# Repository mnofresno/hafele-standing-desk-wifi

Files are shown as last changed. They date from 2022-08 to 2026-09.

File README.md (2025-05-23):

# Hafele Standing Desk

## WiFi-Control Modification

### Overview

This project details the steps to modify a Hafele® Standing Desk to be controlled via WiFi.

## Table of Contents

1. [Overview](#overview)
2. [Hardware](#hardware)
   - [Materials](#materials)
   - [Case Design](#case-design)
   - [Renders of the Case](#renders-of-the-case)
3. [Software](#software)
   - [Firmware](#firmware)
   - [Firmware Compilation & Deployment](#firmware-compilation--deployment)
4. [System Features](#system-features)
5. [Technical Specifications](#technical-specifications)
6. [Contributing](#contributing)
7. [References](#references)

### Hardware

#### Materials

- **Printing Filament:**
  - Case: Approximately 52 grams and 17.46 meters
  - Lid: Approximately XX grams and YY meters

- **Electronics:**
  - **CPU:** Wemos D1 ESP32, 160~240 MHz, 320 KiB RAM
  - **Display:** OLED 128x64 px i2C SSD1306, viewable area: 14.7x26.7 mm
  - **Relay Module Shield:** 2 CH

#### Case Design

The case was parametrically designed using FreeCAD 0.0.19 with adjustable parameters:

- Length
- Height
- Width
- Display dimensions (width and height)
- Radius of curvature
- Panel angle
- Wall thickness
- Display position (x and y)
- Button distance
- Lid thickness
- Bolt diameter, length, and separation
- Inner diameter of bolt nuts

##### Provided Files

The following files are included in the `plastic_case` directory:

- `control_box.stl`: STL file for the main control box.
- `control_box_lid.stl`: STL file for the lid of the control box.
- `hafele_control_box_with_lid.FCStd`: FreeCAD source file for the control box and lid.
- `control_box_render.png`: Rendered image of the control box.
- `control_box_lid_render.png`: Rendered image of the control box lid.

#### Renders of the Case

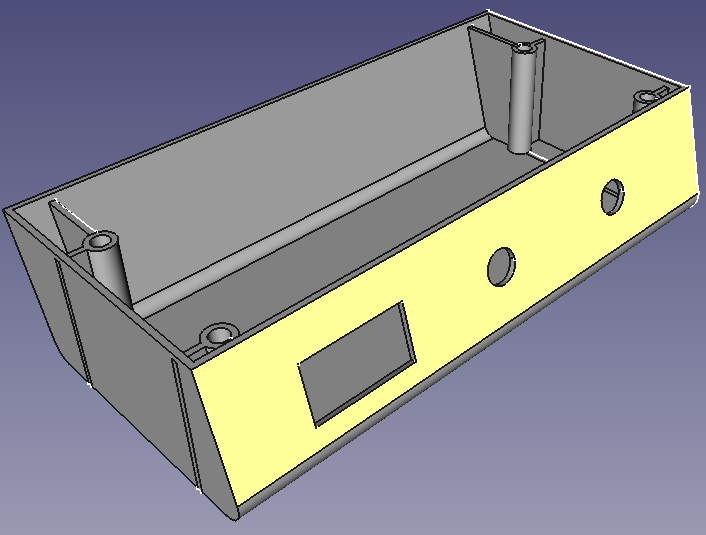
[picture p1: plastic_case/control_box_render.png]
Control Box Render

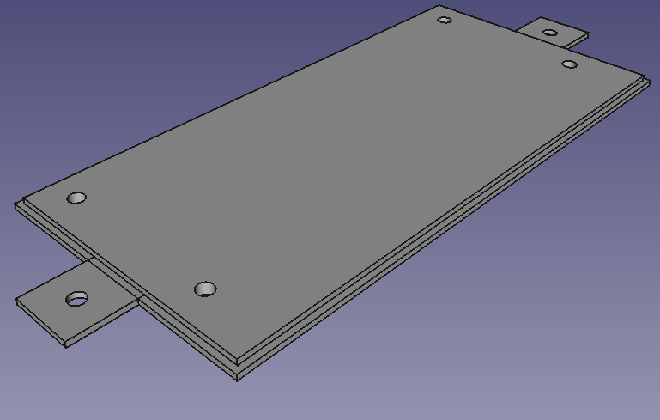
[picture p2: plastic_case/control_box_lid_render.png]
Control Box Lid Render


### Software

#### Firmware

The firmware was developed in Arduino C++, based on the [WiFi Manager platform](https://github.com/tzapu/WiFiManager).

Current version: v1.1.9

#### Firmware Compilation & Deployment

1. **Install Docker:**

   If you don't have Docker installed, follow the instructions [here](https://docs.docker.com/get-docker/).

2. **Compile the Source Code:**

   Run the `build.sh` script to compile the firmware using Docker:

   ```bash
   cd firmware
   ./build.sh
   ```

3. **Compile and Upload with OTA:**

   ```bash
   make TARGET_IP=x.x.x.x
   ```
   (Replace `x.x.x.x` with the device's IP address)

### System Features

#### Core Functionality
- Height adjustment with position memory (M1, M2)
- Real-time clock display
- System calibration
- Lock mode for safety
- Debug mode for troubleshooting

#### User Interface
- OLED display (128x64 pixels)
- Rotary encoder for navigation
- Two control buttons (Enter, Back)
- Intuitive menu system

#### Movement Control
- Continuous up/down movement
- One-second movement increments
- Full up/down positions
- Memory positions (M1, M2)
- Height limits with safety margins

### Technical Specifications

#### GPIO Configuration
- Motor Control:
  - Up Relay: GPIO32
  - Down Relay: GPIO33
- User Interface:
  - Enter Button: GPIO34
  - Back Button: GPIO35
  - Encoder A: GPIO18
  - Encoder B: GPIO19

#### System Limits
- Maximum Height: 1220mm
- Minimum Height: 725mm
- Safety Margin: 5mm

#### WiFi Configuration
- Default AP Name: "WIFI_STANDING_DESK"
- Default AP Password: "PASSWORD"
- Non-blocking configuration portal
- OTA update support

#### Dependencies
- WiFiManager: WiFi configuration
- Adafruit_GFX: Display graphics
- Adafruit_SSD1306: OLED display control
- ESP32Encoder: Rotary encoder handling
- ArduinoJson: JSON processing
- NTPClient: Time synchronization

#### Safety Features
- Watchdog Timer (2-second timeout)
- EEPROM error handling
- Movement limit validation
- Configuration validation
- Emergency stop functionality

### Contributing

For contributions, please send an email to the repository owner.

### References

- Photos of the case
- Screenshots of the STL file designed in FreeCAD

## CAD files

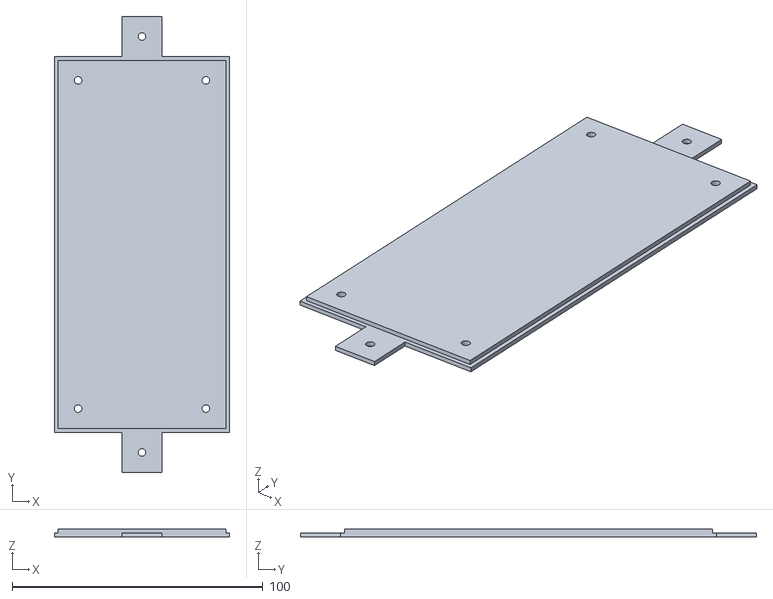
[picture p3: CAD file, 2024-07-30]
plastic_case/control_box_lid.stl
70.0 x 182.0 x 3.00

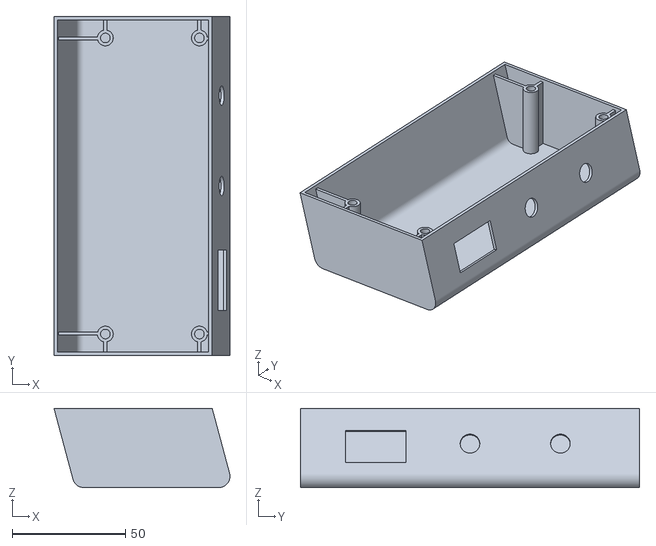
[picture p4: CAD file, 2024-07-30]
plastic_case/control_box.stl
77.9 x 150.0 x 35.0

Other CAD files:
plastic_case/hafele_control_box_with_lid.FCStd

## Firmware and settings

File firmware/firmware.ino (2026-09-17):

#include <assert.h>
#include <WiFiManager.h>
#include <SPI.h>
#include <Wire.h>
#include <Adafruit_GFX.h>
#include <Adafruit_SSD1306.h>
#include <ESP32Encoder.h>
#include <esp_task_wdt.h>
#include <ArduinoJson.h>

#include "MenuInstance.h"
#include "MotorDriver.h"
#include "Calibration.h"
#include "DebugInfo.h"
#include "DisplayHandler.h"
#include "ButtonsHandler.h"
#include "html/panel.h"
#include <WiFiUdp.h>
#include <NTPClient.h>
#include <ESPmDNS.h>
#include <esp_wifi.h>
#define __ASSERT_USE_STDERR

#define VERSION_STRING "v1.2.7"

#define DEFAULT_HOSTNAME "hafele-standing-desk"
#define DEFAULT_AP_NAME "WIFI_STANDING_DESK"
#define DEFAULT_AP_PASSWORD "PASSWORD"

#define SCREEN_WIDTH 128 // OLED display width, in pixels
#define SCREEN_HEIGHT 64 // OLED display height, in pixels

#define OLED_RESET     -1 // Reset pin # (or -1 if sharing Arduino reset pin)

#define STATE_CLOCK 0
#define STATE_MENU 1
#define STATE_WIFI_CONFIG 2
#define STATE_CALIBRATION 3
#define STATE_MEMORIES 4
#define STATE_MOVE 5
#define STATE_DEBUG_CONFIG 6
#define STATE_LOCKED 7

#define ITEM_INDEX_WIFI 1
#define ITEM_INDEX_MEMORIES 101
#define ITEM_INDEX_MOVE 2
#define ITEM_INDEX_DEBUG 3

#define ITEM_INDEX_MOVE_UP 4
#define ITEM_INDEX_MOVE_DOWN 5
#define ITEM_INDEX_MOVE_FULL_UP 6
#define ITEM_INDEX_MOVE_FULL_DOWN 7
#define ITEM_INDEX_MOVE_1SEC_UP 61
#define ITEM_INDEX_MOVE_1SEC_DOWN 71

#define ITEM_INDEX_CALIBRATION 8
#define ITEM_INDEX_CALIBRATION_CURRENT_POSITION 9
#define ITEM_INDEX_CALIBRATION_UP_SPEED 10
#define ITEM_INDEX_CALIBRATION_DOWN_SPEED 11
#define ITEM_INDEX_CALIBRATION_DOWN_STATUS 12
#define ITEM_INDEX_DISPLAY_TIMEOUT 17

#define ITEM_INDEX_MEMORIES_GOTO_M1 13
#define ITEM_INDEX_MEMORIES_GOTO_M2 14
#define ITEM_INDEX_MEMORIES_SET_M1 15
#define ITEM_INDEX_MEMORIES_SET_M2 16

#define UP_RELAY_PIN 32
#define DOWN_RELAY_PIN 33

#define ENTER_BUTTON_PIN 34
#define BACK_BUTTON_PIN 35

#define ENCODER_PIN_A 18
#define ENCODER_PIN_B 19

#define ARRAY_SIZE(array) (sizeof(array)/sizeof((array)[0]))
#define WDT_TIMEOUT 2
#define DISPLAY_TIMEOUT_MIN_SECONDS 0
#define DISPLAY_TIMEOUT_MAX_SECONDS 120
#define DISPLAY_TIMEOUT_STEP_SECONDS 10

ESP32Encoder encoder;
WiFiManager wifiManager;
WiFiManagerParameter wm_param_current_position_mm("current_position_mm", "Current Position (mm)", "position", 20);
WiFiManagerParameter wm_param_up_traverse_mm_sec("up_traverse_mm_sec", "Up traverse speed (mm/s)", "up traverse", 20);
WiFiManagerParameter wm_param_down_traverse_mm_sec("down_traverse_mm_sec", "Down traverse speed (mm/s)", "down traverse", 20);

Adafruit_SSD1306 display(SCREEN_WIDTH, SCREEN_HEIGHT, &Wire, OLED_RESET);
Calibration calibration_storage(&on_corrupted_eeprom);
MotorDriver motor_driver(UP_RELAY_PIN, DOWN_RELAY_PIN);
DisplayHandler display_handler(&display);
ButtonsHandler buttons_handler(ENTER_BUTTON_PIN, BACK_BUTTON_PIN, true);
DebugInfo debug_info(&display_handler, &buttons_handler);
WiFiUDP ntpUDP;
NTPClient timeClient(ntpUDP, "pool.ntp.org", -10800, 3600000);

const char* get_state_name(int state) {
    switch (state) {
        case STATE_CLOCK: return "STATE_CLOCK";
        case STATE_MENU: return "STATE_MENU";
        case STATE_WIFI_CONFIG: return "STATE_WIFI_CONFIG";
        case STATE_CALIBRATION: return "STATE_CALIBRATION";
        case STATE_MEMORIES: return "STATE_MEMORIES";
        case STATE_MOVE: return "STATE_MOVE";
        case STATE_DEBUG_CONFIG: return "STATE_DEBUG_CONFIG";
        case STATE_LOCKED: return "STATE_LOCKED";
        default: return "UNKNOWN_STATE";
    }
}

MenuItem main_menu[] = {
    {ITEM_INDEX_WIFI, "WiFi Cfg."},
    {ITEM_INDEX_CALIBRATION, "Calibr."},
    {ITEM_INDEX_MEMORIES, "Memories"},
    // {ITEM_INDEX_CLOCK, "Clock"},
    {ITEM_INDEX_MOVE, "Move"},
    // {ITEM_INDEX_DEBUG, "Debug"},
};

MenuItem move_menu[] = {
    {ITEM_INDEX_MOVE_UP, "Up"},
    {ITEM_INDEX_MOVE_DOWN, "Down"},
    {ITEM_INDEX_MOVE_FULL_UP, "Full-Up"},
    {ITEM_INDEX_MOVE_FULL_DOWN, "Full-Down"},
    {ITEM_INDEX_MOVE_1SEC_UP, "1 sec. UP"},
    {ITEM_INDEX_MOVE_1SEC_DOWN, "1 sec. DN"},
};

MenuItem calibration_menu[] = {
    {ITEM_INDEX_CALIBRATION_CURRENT_POSITION, "Pos:"},
    {ITEM_INDEX_CALIBRATION_UP_SPEED, "Up:"},
    {ITEM_INDEX_CALIBRATION_DOWN_SPEED, "Dn:"},
    {ITEM_INDEX_CALIBRATION_DOWN_STATUS, "St:"},
    {ITEM_INDEX_DISPLAY_TIMEOUT, "Off:"},
};

MenuItem memories_menu[] = {
    {ITEM_INDEX_MEMORIES_GOTO_M1, "M1 999 mm"},
    {ITEM_INDEX_MEMORIES_GOTO_M2, "M2 111 mm"},
    {ITEM_INDEX_MEMORIES_SET_M1, "Set M1"},
    {ITEM_INDEX_MEMORIES_SET_M2, "Set M2"},
};

MenuInstance main_menu_instance(
    &display_handler,
    main_menu,
    ARRAY_SIZE(main_menu),
    "Menu: (.)",
    &buttons_handler
);

MenuInstance move_menu_instance(
    &display_handler,
    move_menu,
    ARRAY_SIZE(move_menu),
    "Move:",
    &buttons_handler
);

MenuInstance calibration_menu_instance(
    &display_handler,
    calibration_menu,
    ARRAY_SIZE(calibration_menu),
    "Calib:",
    &buttons_handler
);

MenuInstance memories_menu_instance(
    &display_handler,
    memories_menu,
    ARRAY_SIZE(memories_menu),
    "Mem:",
    &buttons_handler
);

int current_state = STATE_MENU;
int next_state = STATE_MENU;
static bool wdt_is_enabled = false;
CalibrationData calibration;
bool is_wifi_enabled = true;
int use_ap_or_station = WIFI_STA;
bool is_display_locked = false;
bool wifi_currently_connected = false;
unsigned long last_display_activity_millis = 0;
int64_t last_activity_encoder_position = 0;
int last_activity_enter_level = HIGH;
int last_activity_back_level = HIGH;
bool display_is_off = false;

void on_corrupted_eeprom() {
    display_handler.print_full_screen_with_title("Invalid Cfg.", "Restore default...");
}

void setup() {
    Serial.begin(115200);
    Serial.println();
    Serial.println("Starting Serial Port...");

    display_handler.draw_starting(VERSION_STRING);
    config_inputs_and_outputs();

    ESP32Encoder::useInternalWeakPullResistors=UP;
  	encoder.attachHalfQuad(ENCODER_PIN_B, ENCODER_PIN_A);

    last_activity_encoder_position = encoder.getCount();
    last_activity_enter_level = digitalRead(ENTER_BUTTON_PIN);
    last_activity_back_level = digitalRead(BACK_BUTTON_PIN);
    last_display_activity_millis = millis();

    WiFi.mode(WIFI_STA);
    WiFi.setHostname(DEFAULT_HOSTNAME);
    MDNS.begin(DEFAULT_HOSTNAME);

    calibration_storage.fetch(calibration);

    setup_wifi_manager();

    calibration_menu_instance.setFontSize(2);

    motor_driver.setOnCalibrationChangedCallback(&store_calibration);
    motor_driver.setCalibrationData(&calibration);
    timeClient.begin();
}

void setup_wifi_manager() {
    wifiManager.setConfigPortalBlocking(false);

    wifiManager.setPreOtaUpdateCallback(&on_pre_ota_update);
    wifiManager.setTitle("WIFI STANDING DESK");

    update_calibration_parameters();

    wifiManager.setParamsPage(true);
    wifiManager.setSaveParamsCallback(&on_params_save);
    wifiManager.addParameter(&wm_param_current_position_mm);
    wifiManager.addParameter(&wm_param_up_traverse_mm_sec);
    wifiManager.addParameter(&wm_param_down_traverse_mm_sec);

    wifiManager.setWebServerCallback(&config_api_endpoints);

    wifiManager.startWebPortal();
}

void update_calibration_parameters() {
    wm_param_current_position_mm.setValue(String(calibration.current_position_mm).c_str(), 20);
    wm_param_up_traverse_mm_sec.setValue(String(calibration.up_traverse_mm_sec).c_str(), 20);
    wm_param_down_traverse_mm_sec.setValue(String(calibration.down_traverse_mm_sec).c_str(), 20);
}

void store_calibration() {
    update_calibration_parameters();
    calibration_storage.store(calibration);
    motor_driver.setCalibrationData(&calibration);
}

void on_params_save() {
    calibration.current_position_mm = String(wm_param_current_position_mm.getValue()).toInt();
    calibration.up_traverse_mm_sec = String(wm_param_up_traverse_mm_sec.getValue()).toInt();
    calibration.down_traverse_mm_sec = String(wm_param_down_traverse_mm_sec.getValue()).toInt();
    store_calibration();
}

void on_pre_ota_update() {
    disable_wdt();
    display.clearDisplay();
    display_handler.print_full_screen_with_title("FW UPDATE", "Please wait...");
}

void config_inputs_and_outputs() {
    pinMode(DOWN_RELAY_PIN, OUTPUT);
    pinMode(UP_RELAY_PIN, OUTPUT);
}

String generate_json_status() {
    DynamicJsonDocument parsedStatus(2048);
    parsedStatus["current_position_mm"] = calibration.current_position_mm;
    parsedStatus["memory_m1_mm"] = calibration.memory_m1_mm;
    parsedStatus["memory_m2_mm"] = calibration.memory_m2_mm;
    parsedStatus["is_display_locked"] = is_display_locked;
    parsedStatus["display_timeout_seconds"] = calibration.display_timeout_seconds;
    parsedStatus["is_moving"] = motor_driver.isMoving();
    parsedStatus["wifi_ssid"] = wifiManager.getWiFiSSID();
    parsedStatus["current_state"] = get_state_name(current_state);
    parsedStatus["hostname"] = DEFAULT_HOSTNAME;
    parsedStatus["version"] = VERSION_STRING;
    String jsonStatus;
    serializeJson(parsedStatus, jsonStatus);
    return jsonStatus;
}

void toggle_lock() {
    if (is_display_locked) {
        is_display_locked = false;
        next_state = STATE_MENU;
    } else {
        is_display_locked = true;
    }
}

void config_api_endpoints() {
    wifiManager.server->on("/status", [&]() {
        wifiManager.server->send(200, "application/json", generate_json_status());
    });

    wifiManager.server->on("/stop", [&]() {
        motor_driver.stop();
        wifiManager.server->send(200, "text/html charset=utf-8", htmlPanelWithMessage("Stopped"));
    });

    wifiManager.server->on("/up", [&]() {
        motor_driver.moveUpForMillis(700);
        wifiManager.server->send(200, "text/html charset=utf-8", htmlPanelWithMessage("Moving UP"));
    });

    wifiManager.server->on("/toggle_lock", [&]() {
        toggle_lock();
        wifiManager.server->send(200, "application/json", generate_json_status());
    });

    wifiManager.server->on("/down", [&]() {
        motor_driver.moveDownForMillis(600);
        wifiManager.server->send(200, "text/html charset=utf-8", htmlPanelWithMessage("Moving DOWN"));
    });

    wifiManager.server->on("/full_up", [&]() {
        motor_driver.moveFullUp();
        wifiManager.server->send(200, "text/html charset=utf-8", htmlPanelWithMessage("Moving FULL UP"));
    });

    wifiManager.server->on("/full_down", [&]() {
        motor_driver.moveFullDown();
        wifiManager.server->send(200, "text/html charset=utf-8", htmlPanelWithMessage("Moving FULL DOWN"));
    });

    wifiManager.server->on("/move_to", [&]() {
        String position_str = wifiManager.server->arg(String("target"));
        if (position_str.length() > 0) {
            int position = position_str.toInt();
            motor_driver.moveToTarget(position);
            wifiManager.server->send(200, "text/html charset=utf-8", htmlPanelWithMessage("Moving to target: " + String(position)));
            return;
        }
        wifiManager.server->send(200, "text/html charset=utf-8", htmlPanelWithMessage("NOWHERE: Error, must include target query param"));
    });

    wifiManager.server->on("/panel", [&]() {
        wifiManager.server->send(200, "text/html charset=utf-8", htmlPanelWithMessage(""));
    });
}

String htmlPanelWithMessage(String message) {
    String htmlPage(HTML_PANEL);
    htmlPage.replace("%message%", message);
    return htmlPage;
}

void enable_wdt() {
    if (!wdt_is_enabled) {
        esp_task_wdt_init(WDT_TIMEOUT, true); //enable panic so ESP32 restarts
        esp_task_wdt_add(NULL); //add current thread to WDT watch
        wdt_is_enabled = true;
    }
}

void disable_wdt() {
    if (wdt_is_enabled) {
        esp_task_wdt_init(60, false); //enable panic so ESP32 restarts
        esp_task_wdt_add(NULL); //add current thread to WDT watch
        wdt_is_enabled = false;
    }
}

int menu_item_to_state(int selected_item) {
    switch (selected_item) {
        case MENU_ITEM_GO_BACK:
            return STATE_CLOCK;
        case ITEM_INDEX_WIFI:
            return STATE_WIFI_CONFIG;
        case ITEM_INDEX_CALIBRATION:
            return STATE_CALIBRATION;
        case ITEM_INDEX_MEMORIES:
            return STATE_MEMORIES;
        // case ITEM_INDEX_CLOCK:
        //     return STATE_CLOCK;
        case ITEM_INDEX_MOVE:
            return STATE_MOVE;
        case ITEM_INDEX_DEBUG:
            return STATE_DEBUG_CONFIG;
        default:
            return get_default_state();
    }
}

int get_default_state() {
    return is_display_locked
        ? STATE_LOCKED
        : STATE_MENU;
}

void wifi_print_connected() {
    display_handler.println_with_pad("Connected to:");
    display_handler.println_with_pad(String(WiFi.SSID()));
    display_handler.println_with_pad("IP Address:");
    display_handler.println_with_pad(WiFi.localIP().toString());
}

void wifi_print_disconnected() {
    String selector = use_ap_or_station == WIFI_STA ? "<-" : "->";
    display_handler.println_with_pad("Not connected :(");
    display_handler.println_with_pad("Press encoder button");
    display_handler.println_with_pad("to re-connect WiFi.");
    display_handler.println_with_pad("STA " + selector + " AP");
}

void wifi_print_connecting(String connecting_bar) {
    String mode = use_ap_or_station == WIFI_STA ? "STA" : "AP";
    display_handler.println_with_pad("");
    display_handler.println_with_pad("Connecting " + mode + connecting_bar);
    display_handler.println_with_pad("");
    display_handler.println_with_pad("Press BACK to cancel");
}

String this_parameter_is_selected(int current_parameter, int selected_parameter) {
    return current_parameter == selected_parameter ? "> " : "";
}
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
void loop() {
    wifiManager.process();
    update_display_power();
    handle_states_machine();
    debug_info.print();
    int64_t encoder_count = encoder.getCount();

    main_menu_instance.updatePosition(encoder_count);
    move_menu_instance.updatePosition(encoder_count);
    memories_menu_instance.updatePosition(encoder_count);

    motor_driver.run();
    reset_wdt();
    try_to_connect_wifi();
    update_clock();
    report_wifi_on_display();
}

void update_display_power() {
    int64_t encoder_position = encoder.getCount();
    int enter_level = digitalRead(ENTER_BUTTON_PIN);
    int back_level = digitalRead(BACK_BUTTON_PIN);
    bool activity = encoder_position != last_activity_encoder_position
        || enter_level != last_activity_enter_level
        || back_level != last_activity_back_level;

    last_activity_encoder_position = encoder_position;
    last_activity_enter_level = enter_level;
    last_activity_back_level = back_level;

    if (activity) {
        last_display_activity_millis = millis();
        if (display_is_off) {
            display.ssd1306_command(SSD1306_CHARGEPUMP);
            display.ssd1306_command(0x14);
            display.dim(false);
            display.ssd1306_command(SSD1306_DISPLAYON);
            display.display();
            display_is_off = false;
        }
    } else if (!display_is_off
        && calibration.display_timeout_seconds > 0
        && (millis() - last_display_activity_millis
            >= calibration.display_timeout_seconds * 1000UL)) {
        display.ssd1306_command(SSD1306_DISPLAYOFF);
        display_is_off = true;
    }
}

void update_clock() {
    static unsigned long last_clock_update = 0;
    if (millis() - last_clock_update >= 60000 && WiFi.isConnected()) {
        timeClient.update();
        last_clock_update = millis();
    }
}

void reset_wdt() {
    static unsigned long last_wdt_reset = millis();
    if (millis() - last_wdt_reset >= (1000 * WDT_TIMEOUT) / 2) {
        esp_task_wdt_reset();
        last_wdt_reset = millis();
    }
}

void try_to_connect_wifi() {
    static unsigned long last_wifi_check = 0;
    
    if (is_wifi_enabled && !WiFi.isConnected() && wifi_check_timed_out(last_wifi_check)) {
        if (use_ap_or_station == WIFI_STA) {
            WiFi.mode(WIFI_STA);
            WiFi.setHostname(DEFAULT_HOSTNAME);
            wifiManager.autoConnect(DEFAULT_AP_NAME, DEFAULT_AP_PASSWORD);
        } else {
            WiFi.mode(WIFI_AP);
            wifiManager.startConfigPortal(DEFAULT_AP_NAME, DEFAULT_AP_PASSWORD);
        }
        
        last_wifi_check = millis();
    } else if (!is_wifi_enabled) {
        WiFi.disconnect(true);
        WiFi.mode(WIFI_OFF);
    }
}

void report_wifi_on_display() {
    static bool wifi_previously_connected = false;
    wifi_currently_connected = WiFi.isConnected();

    if (wifi_previously_connected != wifi_currently_connected) {
        String state(wifi_currently_connected ? "(c)" : "(!)");
        main_menu_instance.setTitle("Menu: " + state);
        wifi_previously_connected = wifi_currently_connected;
    }
}

bool wifi_check_timed_out(int last_wifi_check) {
    return millis() - last_wifi_check >= 2000;
}

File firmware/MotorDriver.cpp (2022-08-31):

#include "MotorDriver.h"

MotorDriver::MotorDriver(
    uint8_t motor_up_pin,
    uint8_t motor_down_pin
) {
    _motor_up_pin = motor_up_pin;
    _motor_down_pin = motor_down_pin;
}

void MotorDriver::run() {
    _update_position();
    if (
        _current_move_state != _expected_state
    ) {
        switch (_expected_state) {
            case MOVE_STATE_UP:
                doMoveUp();
                break;
            case MOVE_STATE_DOWN:
                doMoveDown();
                break;
            case MOVE_STATE_STOP:
                doStop();
                break;
        }
    }

    if ((isMoving() && timedOut() && _duration != 0) || carriedOut() || reachedTarget()) {
        stop();
    }
}

bool MotorDriver::reachedTarget() {
    return currentPositionInMM() > (_target_position - HEIGHT_MARGIN)
        && currentPositionInMM() < (_target_position + HEIGHT_MARGIN);
}

bool MotorDriver::timedOut() {
    return _elapsed_time() >= _duration;
}

bool MotorDriver::carriedOut() {
    return (_moving_up() && carriedOutMax())
        || (_moving_down() && carriedOutMin());
}

bool MotorDriver::carriedOutMax() {
    return currentPositionInMM() > (MAX_HEIGHT_MM - HEIGHT_MARGIN);
}

bool MotorDriver::carriedOutMin() {
    return currentPositionInMM() < (MIN_HEIGHT_MM + HEIGHT_MARGIN);
}

void MotorDriver::_started_movement() {
    if (_started_movement_at == 0) {
        _started_movement_at = millis();
    }
}

void MotorDriver::moveForMillis(int direction, unsigned long duration) {
    _expected_state = direction;
    _duration = duration;
}

void MotorDriver::moveUpForMillis(unsigned long duration) {
    moveForMillis(MOVE_STATE_UP, duration);
}

void MotorDriver::moveDownForMillis(unsigned long duration) {
    moveForMillis(MOVE_STATE_DOWN, duration);
}

void MotorDriver::doMoveUp() {
    if (carriedOutMax()) {
        return;
    }
    _started_movement();
    // enable_wdt();
    digitalWrite(_motor_up_pin, HIGH);
    digitalWrite(_motor_down_pin, LOW);
    _current_move_state = MOVE_STATE_UP;
}

void MotorDriver::doMoveDown() {
    if (carriedOutMin()) {
        return;
    }
    _started_movement();
    // enable_wdt();
    digitalWrite(_motor_down_pin, HIGH);
    digitalWrite(_motor_up_pin, LOW);
    _current_move_state = MOVE_STATE_DOWN;
}

void MotorDriver::doStop() {
    digitalWrite(_motor_up_pin, LOW);
    digitalWrite(_motor_down_pin, LOW);
    _current_move_state = MOVE_STATE_STOP;
    _initial_position_mm = _calibration->current_position_mm;
    _started_movement_at = 0;
    calibrationChanged();
    // disable_wdt();
}

void MotorDriver::moveUp() {
    _expected_state = MOVE_STATE_UP;
    _duration = 0;
}

void MotorDriver::moveDown() {
    _expected_state = MOVE_STATE_DOWN;
    _duration = 0;
}

void MotorDriver::stop() {
    _expected_state = MOVE_STATE_STOP;
    _duration = 0;
}

void MotorDriver::moveFullDown() {
    moveToTarget(MIN_HEIGHT_MM + HEIGHT_MARGIN);
}

void MotorDriver::moveFullUp() {
    moveToTarget(MAX_HEIGHT_MM - HEIGHT_MARGIN);
}

unsigned int MotorDriver::currentPositionInMM() {
    return _calibration->current_position_mm;
}

void MotorDriver::_update_position() {
    if (isMoving()) {
        _calibration->current_position_mm = _initial_position_mm + _speed() * (_elapsed_time() / 1000.0);
    }
}

unsigned int MotorDriver::_elapsed_time() {
    return millis() - _started_movement_at;
}

int MotorDriver::_speed() {
    return _moving_up()
        ? _calibration->up_traverse_mm_sec
        : -_calibration->down_traverse_mm_sec;
}

bool MotorDriver::_moving_up() {
    return _current_move_state == MOVE_STATE_UP;
}

bool MotorDriver::isMoving() {
    return _moving_up() || _moving_down();
}

bool MotorDriver::_moving_down() {
    return _current_move_state == MOVE_STATE_DOWN;
}

void MotorDriver::setOnCalibrationChangedCallback(std::function<void()> callback) {
    _onCalibrationChangedCallback = callback;
}

void MotorDriver::setCalibrationData(CalibrationData *calibration) {
    _calibration = calibration;
    _initial_position_mm = _calibration->current_position_mm;
}

void MotorDriver::calibrationChanged() {
    if (_onCalibrationChangedCallback != NULL) {
        _onCalibrationChangedCallback();
    }
}

void MotorDriver::moveToTarget(unsigned int position) {
    if (pow(currentPositionInMM() - position, 2) <= pow(HEIGHT_MARGIN, 2)) {
        return;
    }
    assert(
        (position >= MIN_HEIGHT_MM + HEIGHT_MARGIN)
        && (position <= MAX_HEIGHT_MM - HEIGHT_MARGIN)
    );
    _target_position = position;
    _expected_state = currentPositionInMM() < position
        ? MOVE_STATE_UP
        : MOVE_STATE_DOWN;
}

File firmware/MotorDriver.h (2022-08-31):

#ifndef MotorDriver_h
#define MotorDriver_h

#include <Arduino.h>
#include "Calibration.h"

#define MOVE_STATE_UP 1
#define MOVE_STATE_DOWN 2
#define MOVE_STATE_STOP 3

#define MAX_HEIGHT_MM 1220
#define MIN_HEIGHT_MM 725
#define HEIGHT_MARGIN 5

class MotorDriver {
    private:
        uint8_t _motor_up_pin;
        uint8_t _motor_down_pin;
        unsigned long _started_movement_at = 0;
        unsigned long _duration = 0; /** When = 0, implies infinity */
        unsigned int _current_move_state = MOVE_STATE_STOP;
        unsigned int _expected_state = MOVE_STATE_STOP;
        unsigned int _initial_position_mm;
        unsigned int _target_position = 0;
        std::function<void()> _onCalibrationChangedCallback;
        CalibrationData *_calibration;
        void moveForMillis(int direction, unsigned long duration);
        bool timedOut();
        bool carriedOut();
        bool carriedOutMax();
        bool carriedOutMin();
        void doMoveUp();
        void doMoveDown();
        void doStop();
        void _update_position();
        int _speed();
        unsigned int _elapsed_time();
        void _started_movement();
        bool _moving_up();
        bool _moving_down();
        void calibrationChanged();
        bool reachedTarget();

    public:
        MotorDriver(
            uint8_t motor_up_pin,
            uint8_t motor_down_pin
        );
        void setOnCalibrationChangedCallback(std::function<void()> callback);
        void setCalibrationData(CalibrationData *calibration);
        void moveUpForMillis(unsigned long duration);
        void moveDownForMillis(unsigned long duration);
        void moveToTarget(unsigned int position);
        void moveFullUp();
        void moveFullDown();
        void moveUp();
        void moveDown();
        void stop();
        void run();
        bool isMoving();
        unsigned int currentPositionInMM();
};
#endif

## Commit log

2022-07-01 Add list of materials, TOC and software description
2022-07-04 Add encoder library driver
2022-07-09 Fix menu add some finite state machine with many states
    [firmware.ino]
2022-07-10 Invert the turning sense * Add wifi status display
    [firmware.ino]
2022-07-29 Adapt the firmware to the pull-up of the enter button * Remove recursiveness on tryConnectWifi function * Add UP/DOWN pins definitions
2022-07-29 Achieved stability with menu and submenu for up/down movement
    [firmware.ino]
2022-07-29 Avoid repetition of the pin numbers in the menu instance class
    [firmware.ino]
2022-07-29 Fix bug problem * Include some automatic constants calculation * Remove showmessage function unsed * Enable only usable menu items
    [firmware.ino]
2022-08-01 Change version to 102 * Add clearance of debug info * Start selected option with 1
    [firmware.ino]
2022-08-01 Add motor driver and non-blocking time control
2022-08-03 Add basic calibration logic
2022-08-04 Fix bug on MenuInstance.cpp that allows negative array index to work * Add more debugging instrumentation * Add callback calling on calibration class for corruption event
    [Calibration.h, firmware.ino]
2022-08-04 Fix debug info clearance
    [firmware.ino]
2022-08-06 Fix calibration service * Add display set cursor to display handler * Refactor move all ifss for menu translation into switch-case
    [Calibration.h, firmware.ino]
2022-08-06 Add buttons handler tool service abstraction
2022-08-09 Add anti-alliasing both for state change and button pressings
2022-08-28 Add menu font size control * Add calibration menu based on menu class * Remove debug port menu option
2022-08-29 Fix some calibration errors.
    [Calibration.h, MotorDriver.cpp, MotorDriver.h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]
2022-08-29 Fix motor driver handling of overhangs
    [MotorDriver.cpp, MotorDriver.h]
2022-08-31 Fix moving while going to mems
    [MotorDriver.cpp, MotorDriver.h, firmware.ino]
2022-08-31 Fix up/down feature, fix ap name and pass default values
    [MotorDriver.cpp, firmware.ino]
2023-06-09 Fix bug in MenuInstance to avoid assert hang up on menu index overflow * Remove commented code * Fix name of menu instance vars
    [firmware.ino]
2024-03-30 Fix some detials on panel pages
    [firmware.ino]
2024-04-15 Add memories shortcuts to html panel
    [firmware.ino]
2024-07-30 feat(firmware_build): update workflow and documentation for firmware build
    - Dockerized build
    - Rename workflow job from 'test' to 'firmware_build'
    - Change docker build path in workflow to 'firmware/docker-build'
    - Update README.md with detailed WiFi-Control Modification project steps
    - Improve readability and structure of hardware and software sections
    - Add comprehensive Table of Contents
    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
    [control_box.stl, control_box_lid.stl, hafele_control_box_with_lid.FCStd]
2024-08-01 feat(firmware): add display lock functionality and improve UI/UX
    - Added display lock state and toggle endpoint
    - Updated `generate_json_status` to include `is_display_locked`
    - Modified `config_api_endpoints` to handle `/toggle_lock` endpoint
    - Introduced `get_default_state` function to handle default state logic
    - Enhanced `states_transformation` and `handle_states_machine` to manage new `STATE_LOCKED`
    - Updated HTML panel to support display lock toggle and improved UI interactions
    fix(DisplayHandler): adjust anti_flickering default interval
    - Changed default `millis_between_calls` in `anti_flickering` from 100 to 250
    refactor(workflows): add HTML transpilation step
    - Added step to tra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
    [firmware.ino]
2024-08-05 Comment out debug and calibration menues
2024-08-15 fix(firmware): update firmware version and add NTPClient functionality
    - Updated the Docker image version from `1.0.0` to `1.0.1` in the workflow and build scripts.
    - Added `NTPClient` support to keep track of time via NTP server and report the current time in the firmware.
    - Enhanced the locked state display to show the current time and Wi-Fi connection status.
    - Modified `upload.sh` to allow passing a USB port as an argument for more flexible uploads.
    [firmware.ino]
2024-08-18 feat(ui): add stop functionality in motor controls with UI update
    - Introduced a new '/stop' endpoint in the firmware to halt motor activity.
    - Updated the HTML panel to include a "STOP" button with a stop icon for better user experience.
    - Enhanced the CSS to style the stop icon appropriately.
2024-08-18 feat(ui): enhance panel styling and interactivity
    - Improved styles for buttons and text inputs, increasing padding and font sizes for better usability.
    - Introduced accordion functionality for advanced controls, allowing for a collapsible section within the panel.
    - Updated arrow icons for various buttons to make the interface more intuitive.
    - Enhanced dynamic behavior to toggle display lock status with updated icon classes.
2024-08-30 feat(ui): enhance upload feedback and improve movement controls
    - Added response handling for firmware upload in `curl_upload.sh`, providing success or error messages.
    - Updated movement durations in `firmware.ino` for better control responsiveness.
    - Enhanced HTML panel to display status messages and improved button interactions for movement actions.
    - Refactored JavaScript functions to use `fetch` for API calls, improving code readability and error handling.
    [firmware.ino]
2024-09-17 chore(build): update Docker setup and add USB upload functionality
    - Added support for loading environment variables from `build.env` in Docker build scripts.
    - Updated the Docker image tag to version 1.0.2.
    - Implemented `usb_upload.sh` for uploading firmware via USB.
    - Removed deprecated `upload.sh`.
    - Improved error handling in `curl_upload.sh` for better output.
    - Updated dependencies in `Dockerfile` to the latest versions.
    - Increase version to 1.1.6
    [firmware.ino]
2025-04-22 fix: correct WiFi AP/STA mode behavior
    Fixed issue where AP mode was incorrectly functioning as STA mode and vice versa.
    [firmware.ino]
2025-04-27 fix(firmware): update version string and adjust assertion
    - Updated the firmware version string from v1.1.7 to v1.1.8.
    - Adjusted the assertion in `MenuInstance::assert_extra_option` to ensure it aligns with `_total_menu_size`.
    [firmware.ino]
2025-05-03 fix(firmware): actualizar versión y mejorar mensajes de conexión WiFi
    - Se actualizó la cadena de versión del firmware de v1.1.8 a v1.1.9.
    - Se mejoró el mensaje de conexión para incluir el modo (AP o STA) y se añadió la opción de cancelar la conexión.
    [firmware.ino]
2025-05-23 feat(doc): add system documentation and technical specifications
    - Added detailed documentation files for architecture, debug system, motor control, user interface, and WiFi connectivity.
    - Introduced new sections in README.md for system features and technical specifications.
    - Updated README.md with current firmware version and enhanced deployment instructions.
2025-05-23 feat(firmware): add back button long press detection and unit tests
    - Added support for detecting long presses on the back button in ButtonsHandler.
    - Introduced new member variables to track the state and timing of the back button press.
    - Implemented a new method `readBackButtonLongPress()` to check for long presses.
    - Added unit tests for the back button long press functionality in `ButtonsHandler_test.cpp`.
    - Created a script `run_tests.sh` to compile and execute the unit tests.
2025-05-23 refactor(firmware): restructure build and test workflow
    - Renamed "Build arduino firmware" step to "Build and test firmware" for clarity.
    - Removed separate unit test step, now handled within the firmware build process.
    - Added test compilation to the build workflow for integrated testing.
    - Updated build.sh to include test compilation and execution.
2026-09-03 fix(firmware): trigger lock from main menu on back button long press
    [firmware.ino]
2026-09-03 fix(firmware): fix display wake up charge pump, disable auto-off by default, and reset menu selection
    [Calibration.h, firmware.ino]
2026-09-05 fix(firmware): restore display wake after inactivity lock
    [firmware.ino]
2026-09-17 fix(firmware): prevent display init deadlock and restore normal brightness
    [firmware.ino]
2026-09-17 fix(firmware): clean up hostname and MDNS configuration
    [firmware.ino]
2026-10-25 Add native OpenSCAD enclosure reconstruction and validation
2026-10-25 Refine panel cuts, end supports, and lid holes
2026-10-25 Use source support profiles in OpenSCAD case
2026-10-25 Document enclosure fit issues from photos
2026-10-25 feat(cad): add enclosure hardware rework and fit coupons
2026-10-26 Add printable Häfele enclosure rework candidate (#7)
    * Add printable enclosure rework candidate and validation
    * Fix source-aligned panel and support positions
    * Record valid parametric comparison results
    * Add photo-driven enclosure features and fit corrections
    ---------
2026-10-26 Fix encoder carrier clearance and tower chord geometry
2026-10-26 fix(cad): repair enclosure assembly and validation gates
2026-10-26 feat(cad): prototype captive cancel button and document common bracket inputs
2026-10-26 feat(cad): integrate measured controls bracket, board clamps, and clearance validation
